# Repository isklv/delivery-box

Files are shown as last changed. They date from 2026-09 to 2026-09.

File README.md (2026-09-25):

# Parcel Drop Box — Secure Courier Delivery Box

A sheet-metal parcel box in the style of the 3FlexHome "Large Parcel Drop
Box — Top Access", designed so that **what goes in cannot come back out**
except through the owner's locked door.

- **Hinged top flap (top access)** — couriers drop parcels in from above.
- **One-way anti-fishing trap** — a spring-returned plate 170 mm below the
  rim that rotates downward only.
- **Concealed 4-point cam lock** on the front retrieval door — no hasp, no
  shackle, nothing to cut.
- **Anti-pry, anti-lift, anchorable** — inset door in a rebated frame, dog
  bolts on the hinge edge, welded floor, four M12 ground anchors and two
  wall brackets.

Built parametrically in [FreeCAD](https://www.freecad.org).
Russian version with a detailed walk-through of the mechanisms:
[README.ru.md](README.ru.md).

## How the protection works

| Attack | Countermeasure |
|---|---|
| Reaching in through the drop flap | `TrapDoor` closes the throat 170 mm down; parcels then sit a further 780 mm below it, out of arm's reach |
| Fishing a parcel back out with a hook, wire loop or sticky tape | The trap is a **one-way** valve: `TrapStops` block it from ever rotating above horizontal, so it can be pushed down but never pulled up. Anything lifted against it only jams it harder shut |
| Prying the top flap | 18 mm overhang + 14 mm return skirt on three sides, and the `ThroatCollar` turns the rim into a closed box section with no exposed edge |
| Bending the flap back for a straight shot into the box | Stop tabs on `FlapHinge` limit the swing to ~85° |
| Cutting a padlock | There is none. `CamLock` is a concealed cylinder in the door face; a quarter turn lifts `LockBar`, whose four lugs slide in behind the frame keeps |
| Prying the retrieval door | The door is an **inset pan** in a rebated frame (`DoorFrame`): a 2 mm gap, a 10 mm return on every edge, and an 18 mm flange behind it. Nothing to hook a bar behind, and it cannot be pushed in |
| Grinding the door hinges off | Three `DogBolts` on the hinge edge stay engaged in keeps in the frame — removing the hinges does not free the door |
| Levering the box up off its base | The floor is a welded 3 mm plate, not a panel — there is no seam underneath |
| Carrying the whole box away | Four M12 ground-anchor bosses under the floor, reachable only with the door open, plus two `WallBrackets` for bolting to a wall or post |
| Rain and standing water | Flap overhang, collar return, four floor drains, open-bottomed plinth |

## Dimensions

| Parameter | Value |
|---|---|
| Outer width × depth | 410 × 350 mm (414 × 354 over the corner ribs) |
| Overall height | 998 mm (40 plinth + 950 body + flap) |
| Clear drop opening | 356 × 296 mm |
| Trap plane | 170 mm below the rim |
| Parcel chamber | 406 × 344 × 780 mm |
| Retrieval door opening | 340 × 670 mm, sill 60 mm above the floor |
| Wall / flap sheet | 2 mm steel |
| Plinth, floor, door, trap sheet | 3 mm steel |
| Mass (steel only) | ≈ 52 kg |

## Parts

| Part | Role |
|---|---|
| `Plinth` | 40 mm perimeter base: feet, floor support ledge, four anchor bosses |
| `Floor` | Welded 3 mm floor plate, 4 drains, 4 recessed anchor holes |
| `Body` | 4 walls + corner ribs, open top, door opening in the front wall |
| `DoorFrame` | Rebate frame behind the opening + four lock keeps + three dog-bolt keeps |
| `WallBrackets` | Two slotted brackets for bolting the box to a wall or post |
| `ThroatCollar` | 25 mm inward flange + 40 mm return at the rim (stiffener / anti-pry) |
| `TopFlap` | Courier drop flap, 18 mm rain overhang, anti-pry skirt |
| `FlapHinge` | Rear piano hinge with stop tabs (~85° swing limit) |
| `FlapLatch` | Front drop latch |
| **`TrapDoor`** | **One-way anti-fishing trap, cranked rear hinge** |
| `TrapHinge` | Trap pin and fixed leaves, interleaved with the trap knuckles |
| `TrapSprings` | Two torsion springs that return the trap to closed |
| `TrapStops` | Ledges on three walls + rear cover: the trap can never rise above horizontal |
| `FrontDoor` | Inset retrieval door: pan, stiffener ribs, hinge leaves, handle |
| `DoorHinges` | Three wall leaves and pins |
| `DogBolts` | Three anti-lift pins on the hinge edge |
| `LockBar` | Vertical bar with four lugs and the cam yoke — the locking element |
| `CamLock` | Concealed cylinder; a quarter turn lifts the bar 22 mm |

## Drawings

Dimensioned sheets, generated from the same model by `drawings.py`:

| Sheet | |
|---|-|
| [01 General arrangement](drawings/01_general_arrangement.svg) | front / right / plan, overall sizes |
| [02 Trap mechanism](drawings/02_trap_mechanism.svg) | sections B-B and C-C, swing envelope, spring notes |
| [03 Lock mechanism](drawings/03_lock_mechanism.svg) | door from inside, keep section D-D, cam section E-E |

## Files

- `cad/ParcelDropBox.FCStd` — FreeCAD document, closed / armed
- `cad/ParcelDropBoxOpen.FCStd` — flap back, trap tripped, door swung open
- `cad/ParcelDropBox.step` — STEP export of all 18 parts
- `cad/verify.txt` — solid validity, interference and mass report, both states
- `drawings/*.svg` — dimensioned drawings
- `build_box.py` — parametric FreeCAD script (all states)
- `drawings.py` — generates the drawing sheets
- `render.py` — regenerates `images/`
- `images/` — rendered views

## Views

Closed:

| Isometric | Front | Bottom | Right |
|---|---|---|---|
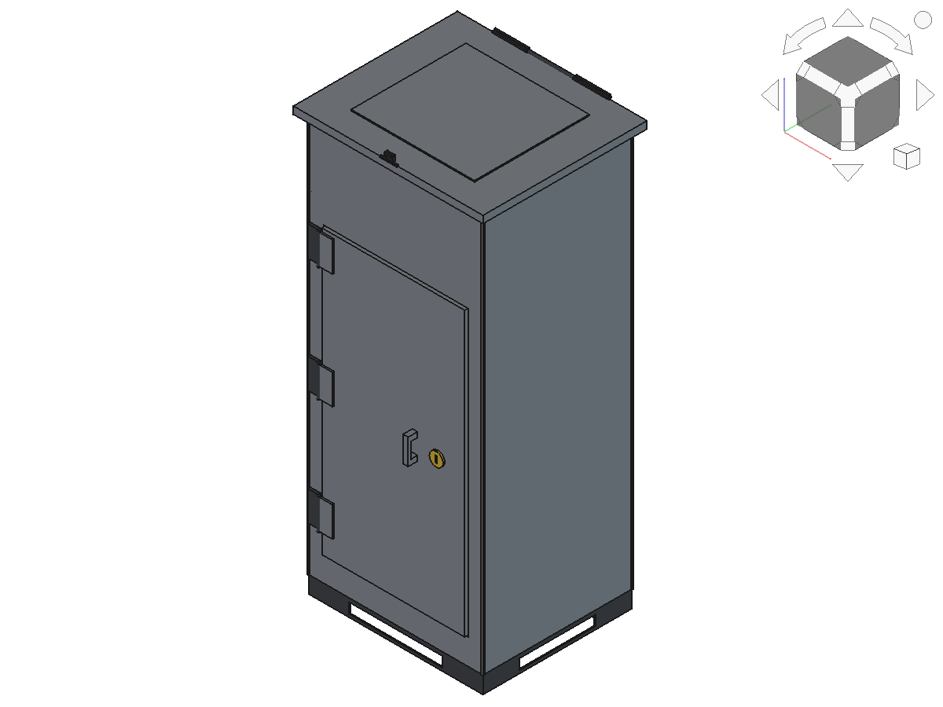
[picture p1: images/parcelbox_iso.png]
iso
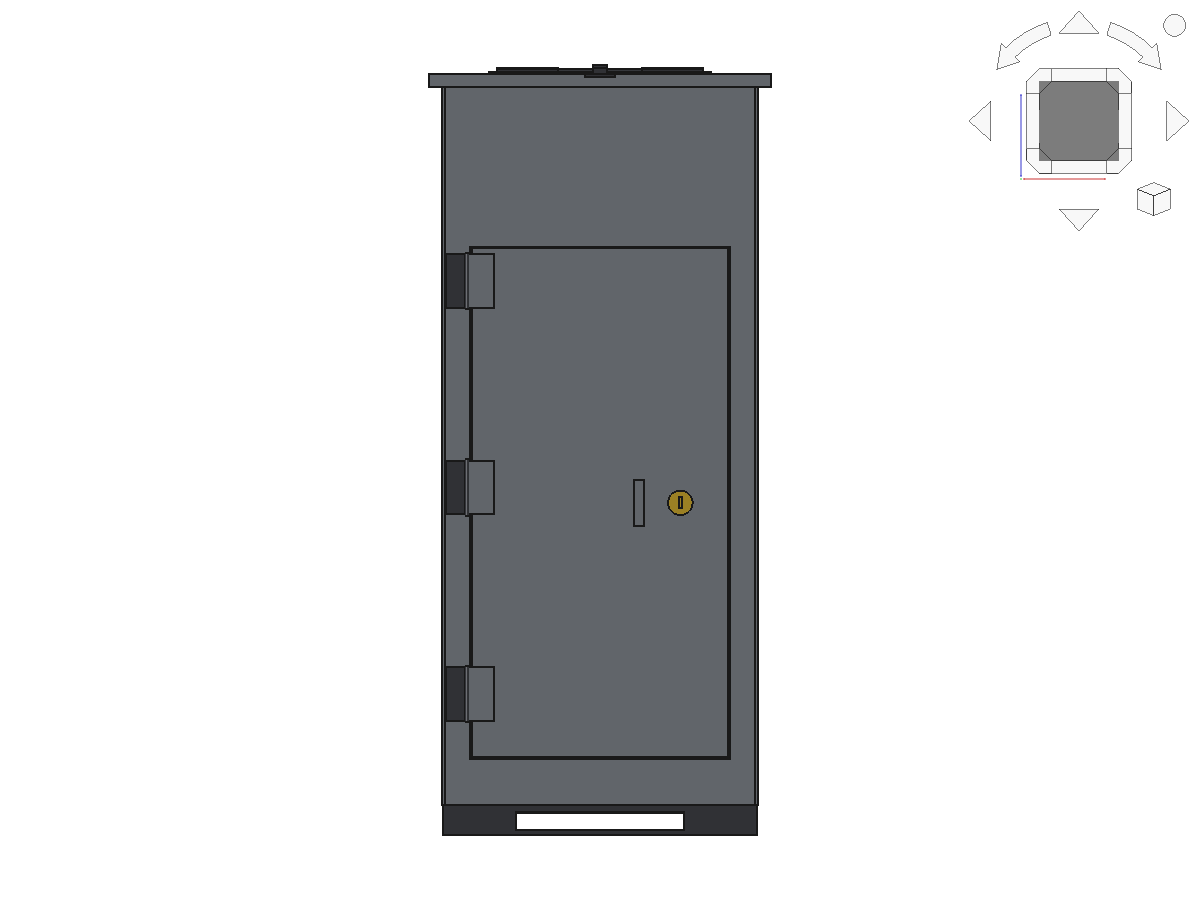
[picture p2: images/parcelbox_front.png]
front
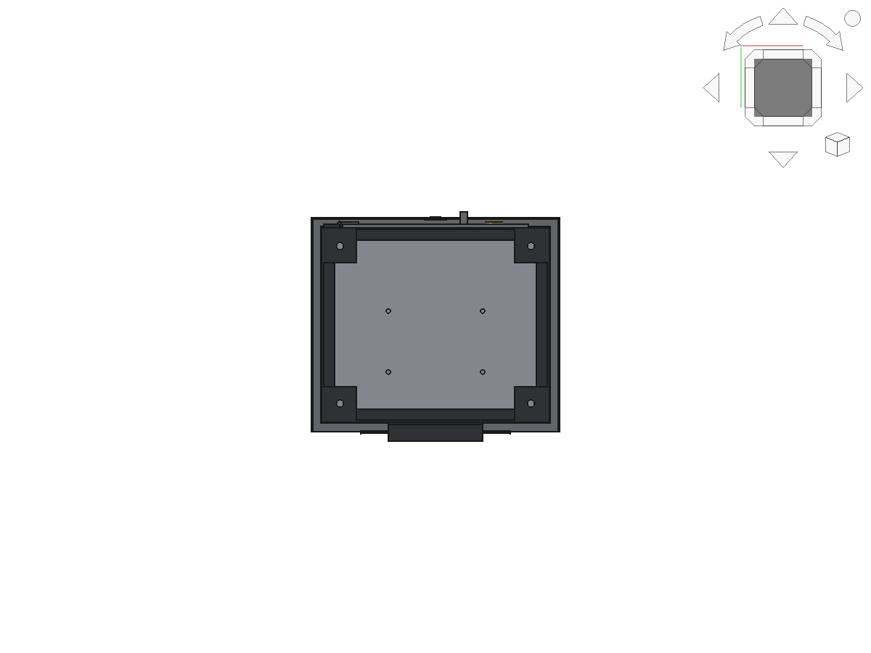
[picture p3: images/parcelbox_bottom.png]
bottom
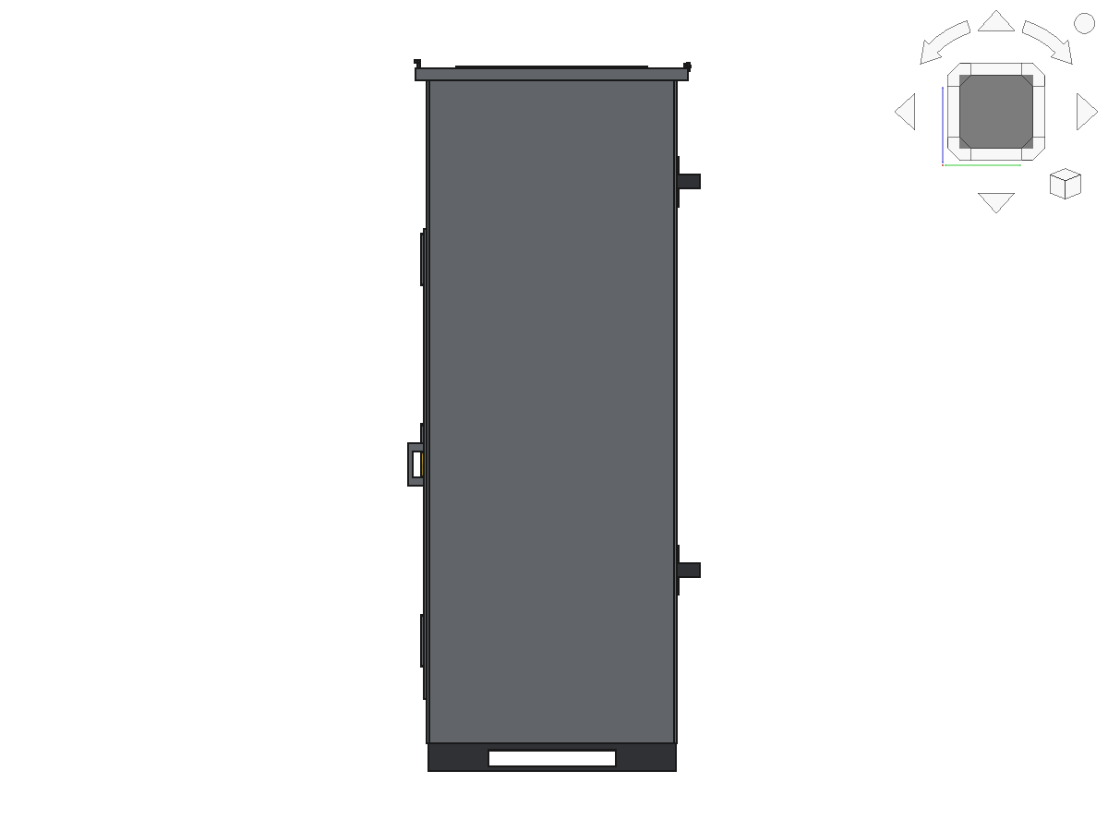
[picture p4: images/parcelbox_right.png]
right
|  |  |  |  |

Section on the X mid-plane — trap, springs, frame keeps and lock bar:

| Isometric | Side |
|---|---|
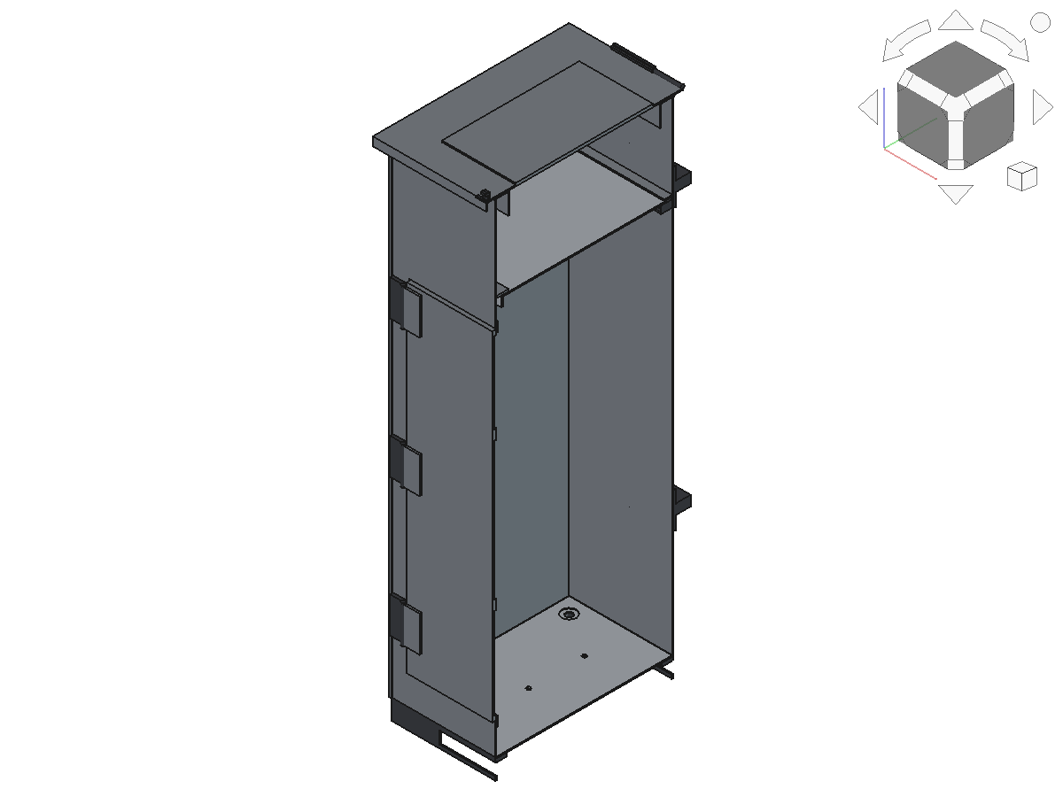
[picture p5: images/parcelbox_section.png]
section
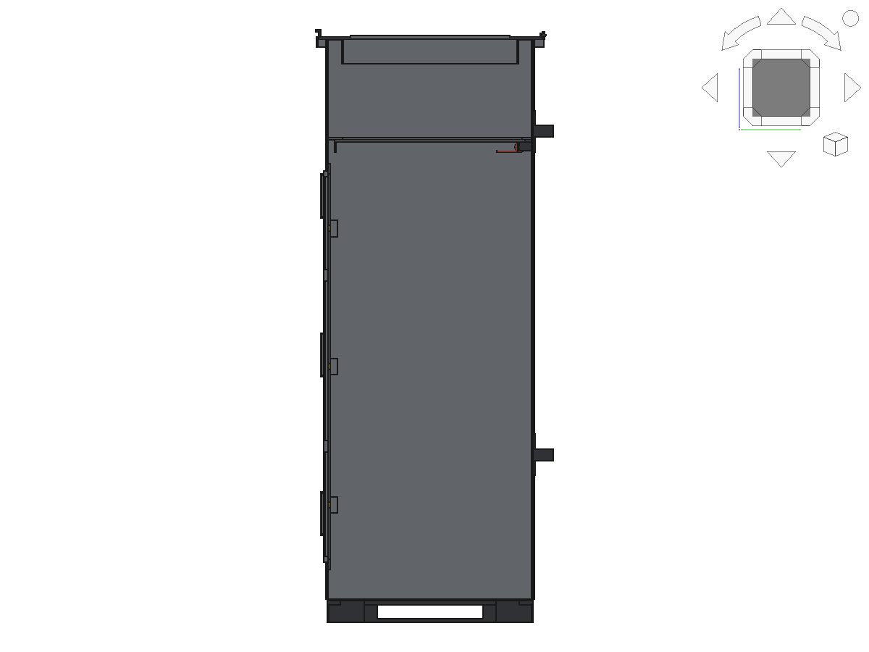
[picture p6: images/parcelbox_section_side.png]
section side
|  |  |

Mechanism close-ups — the one-way trap and the four-point lock:

| Trap, cut away | Trap, side | Lock, behind the door skin |
|---|---|---|
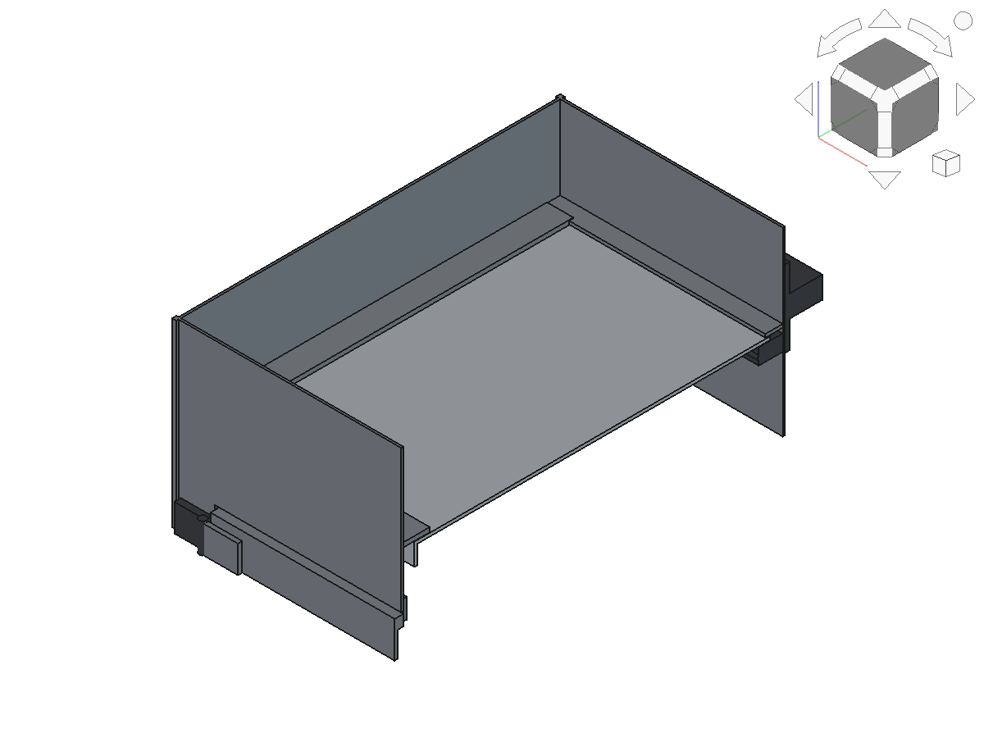
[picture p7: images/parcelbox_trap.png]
trap
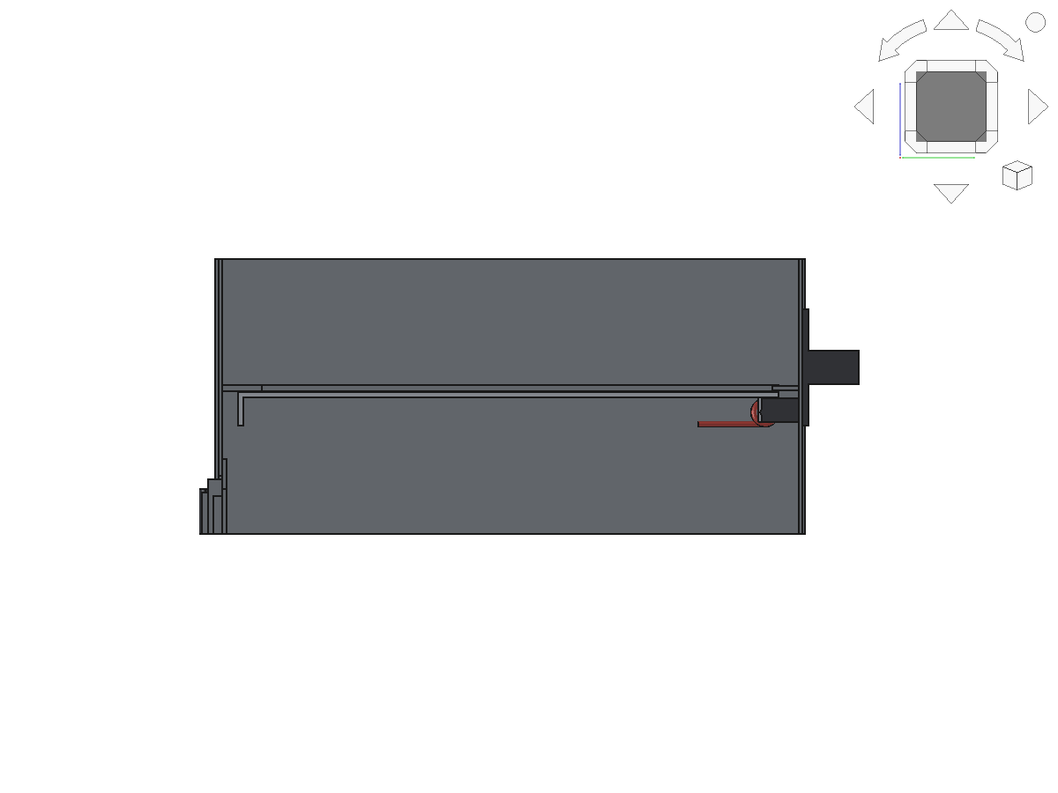
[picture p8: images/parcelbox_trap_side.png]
trap side
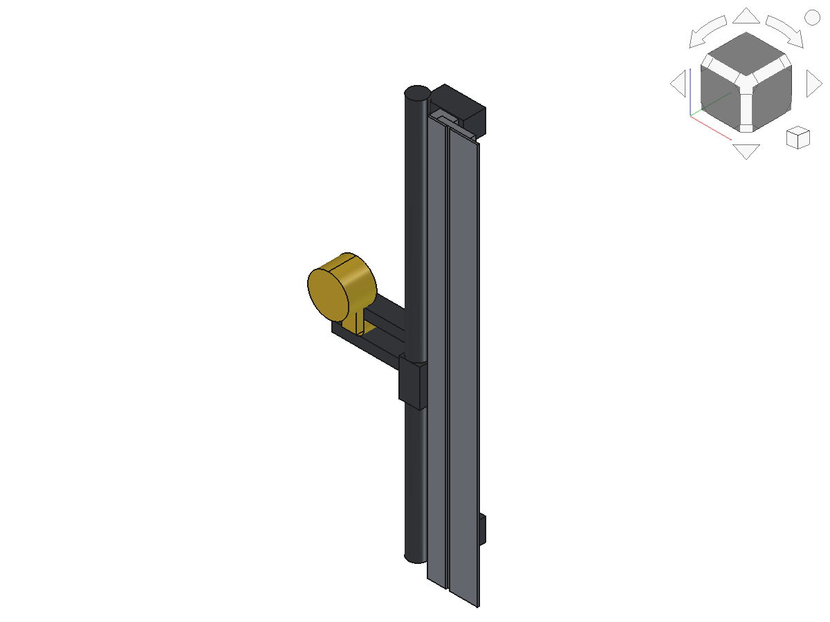
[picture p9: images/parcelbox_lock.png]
lock
|  |  |  |

Open — flap back, trap pushed open by a parcel, retrieval door swung wide:

| Isometric | Front | Back |
|---|---|---|
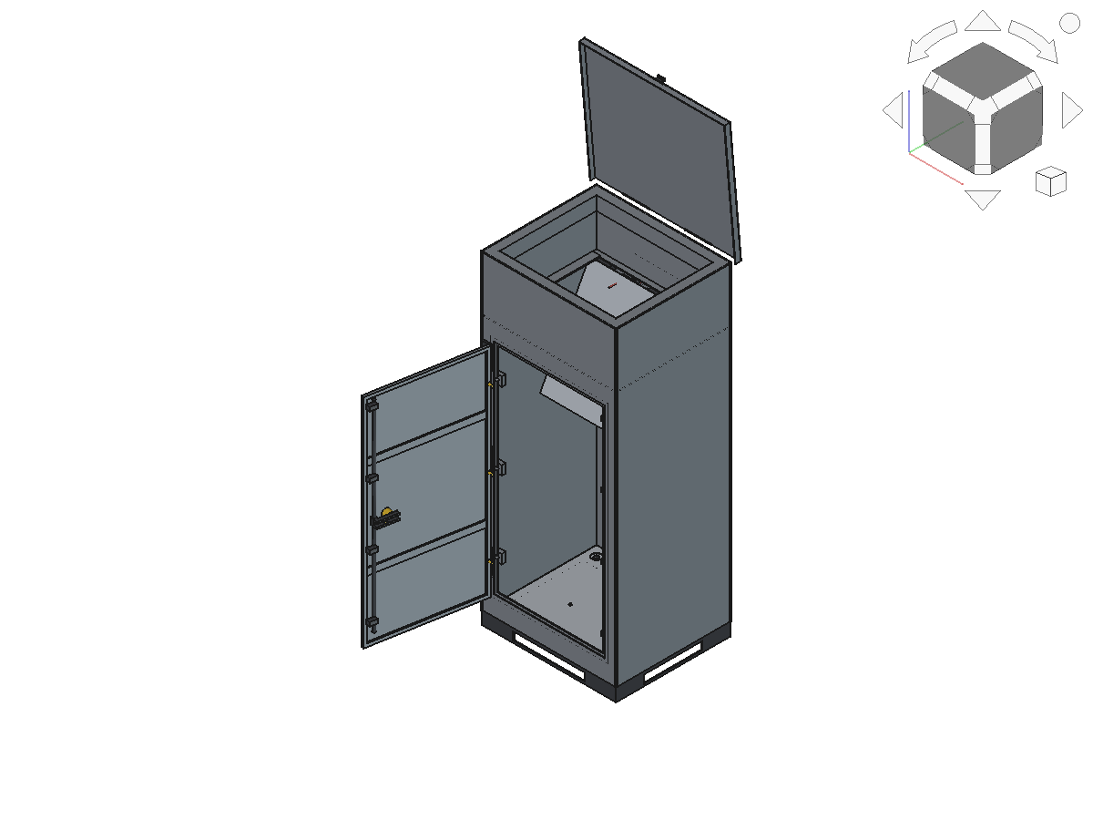
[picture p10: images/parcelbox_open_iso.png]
open iso
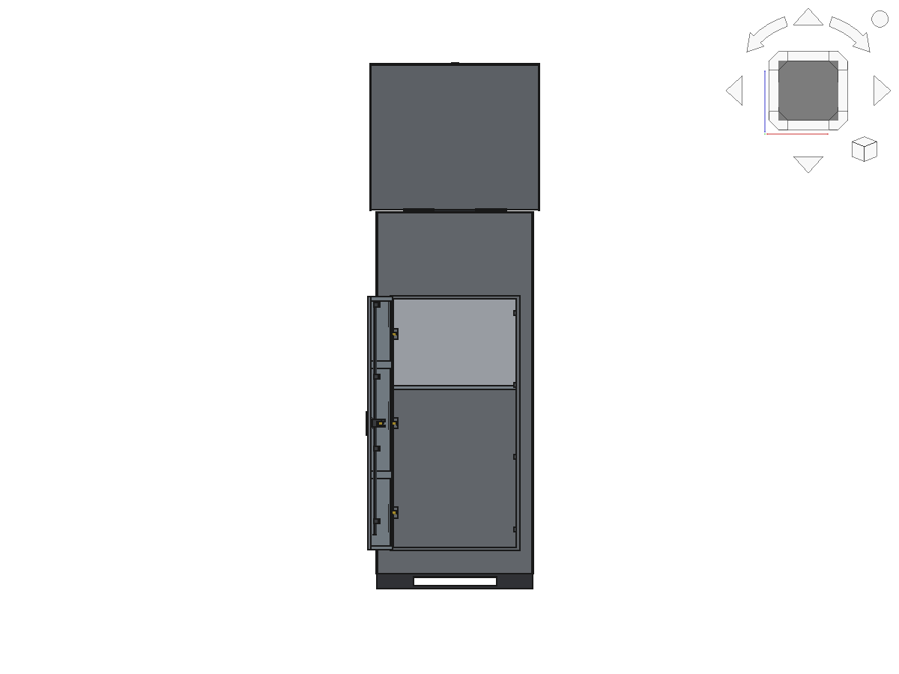
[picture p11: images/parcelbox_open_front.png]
open front
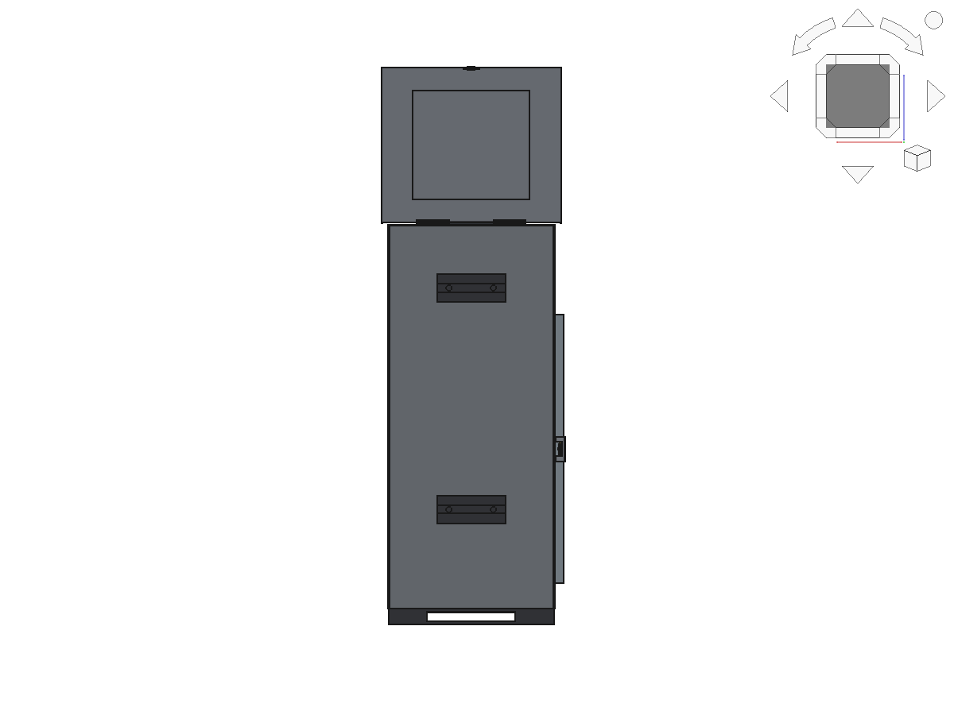
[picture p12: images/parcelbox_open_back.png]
open back
|  |  |  |

## Regenerate

```sh
FreeCADCmd build_box.py                     # geometry, STEP and verify.txt
FreeCADCmd drawings.py                      # dimensioned sheets in drawings/

# images (headless); keep stdin open, FreeCAD's console quits on EOF
sleep 400 | LIBGL_ALWAYS_SOFTWARE=1 \
    xvfb-run -a -s "-screen 0 1600x1200x24" FreeCAD -c render.py
```

On a desktop, `FreeCAD -c render.py` is enough. Both scripts write next to
themselves, into `cad/` and `images/`; `render.py` builds the geometry in
memory and does not touch `cad/`.

## Design and build notes

- **Trap spring tuning is the one adjustment that matters.** The trap is a
  3 mm plate of about 2.3 kg hinged at the rear, so gravity alone would
  leave it hanging open. The two torsion springs must hold it shut and
  still yield to a light parcel; anchor the reaction leg on a slotted
  bracket so the preload can be set on assembly. Aim for a trap that a
  500 g parcel opens.
- The trap hinge is **cranked** — the pin sits 12 mm below the plate — so
  the plate clears its own stop ledges as it swings and cannot be levered
  off the pin from above.
- The trap knuckles and the fixed hinge leaves **interleave** along the
  pin like a piano hinge; weld the pin ends over so it cannot be driven
  out from the throat.
- Weld the `TrapStops` ledges continuously, not in tacks: they are what
  turns the trap from a flap into a one-way valve.
- The lock bar is thrown **upward** to lock. Each lug then sits behind a
  keep on the frame; with the bar down the lugs pass clear, so the door
  closes without forcing anything.
- The 60 mm sill under the door opening keeps parcels from tumbling out
  when the door is opened on a full box.
- Ground anchors go in first: the M12 bosses are only reachable through
  the open door, which is also why they cannot be undone from outside.
- All 18 solids are verified valid in both states with no unintended
  interference; the only overlaps are hinge pins inside their knuckles and
  welded joints (see `cad/verify.txt`).

## What this does not stop

An angle grinder, a battery reciprocating saw, or a vehicle and a chain
will get through any 2–3 mm sheet-steel box, this one included. The design
targets the realistic threat — an opportunist reaching or fishing through
the delivery opening, levering the doors, or walking off with the whole
box — and makes those attacks fail. Anchor it, and site it where a noisy
attack is not private.

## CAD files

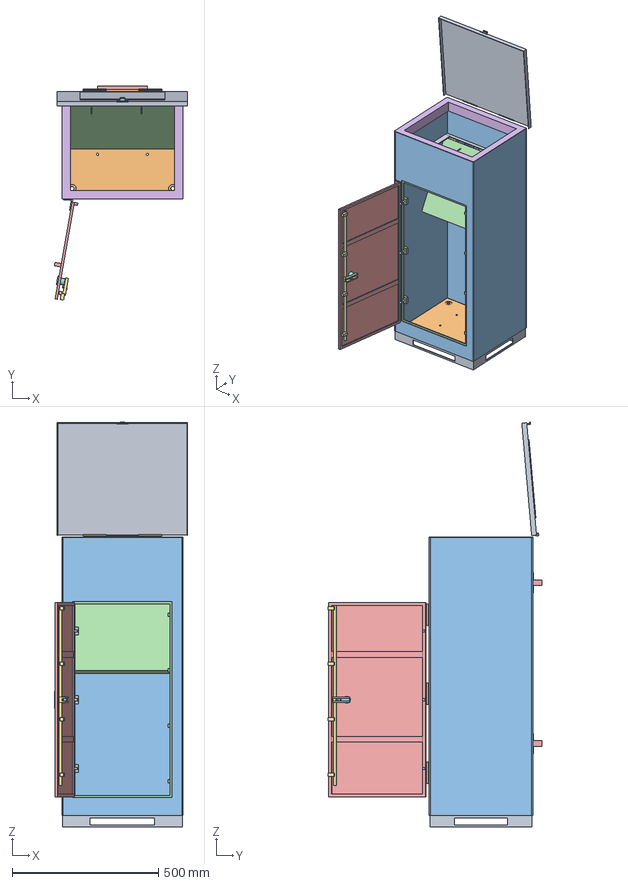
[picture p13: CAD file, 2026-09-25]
cad/ParcelDropBoxOpen.FCStd
455.6 x 732.3 x 1384.4 mm
TopFlap
FlapHinge
FlapLatch
TrapDoor
FrontDoor
DogBolts
LockBar
CamLock
Plinth
Floor
DoorFrame
WallBrackets
ThroatCollar
TrapHinge
TrapSprings
TrapStops
DoorHinges

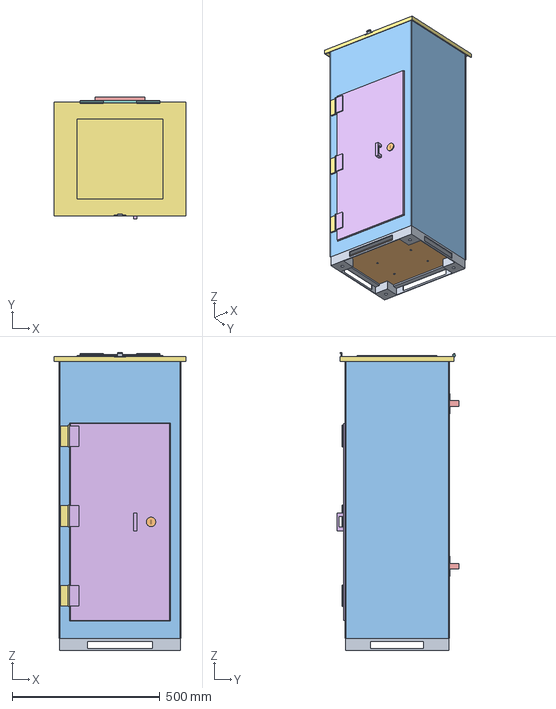
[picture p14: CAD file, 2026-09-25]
cad/ParcelDropBox.step
446.0 x 412.0 x 1008.0 mm

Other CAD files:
cad/ParcelDropBox.FCStd

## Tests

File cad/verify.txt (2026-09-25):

=== closed / armed ===
part                 valid   volume cm3   bbox z
Plinth               True       778.8        0..40    
Floor                True       411.7       37..40    
Body                 True      2462.8       40..990   
DoorFrame            True       131.2       90..780   
WallBrackets         True       284.4      250..870   
ThroatCollar         True       187.3      950..992   
TopFlap              True       785.4      978..998   
FlapHinge            True        18.1      992..1004  
FlapLatch            True         1.7      992..1008  
TrapDoor             True       416.0      800..820   
TrapHinge            True        47.5      802..816   
TrapSprings          True         7.4      797..819   
TrapStops            True       117.1      820..824   
FrontDoor            True       856.3      102..768   
DoorHinges           True        43.2      148..762   
DogBolts             True         1.8      196..674   
LockBar              True        68.3      120..735   
CamLock              True        12.5      409..451   

clamp TopFlap / FlapHinge : 1185.1 mm3
clamp TopFlap / FlapLatch : 480.0 mm3
clamp TrapDoor / TrapHinge : 3273.0 mm3
clamp FrontDoor / DoorHinges : 2771.1 mm3
steel mass approx 52.1 kg

=== open (flap back, trap tripped, door swung) ===
part                 valid   volume cm3   bbox z
Plinth               True       778.8        0..40    
Floor                True       411.7       37..40    
Body                 True      2462.8       40..990   
DoorFrame            True       131.2       90..780   
WallBrackets         True       284.4      250..870   
ThroatCollar         True       187.3      950..992   
TopFlap              True       785.4      996..1382  
FlapHinge            True        18.1      994..1004  
FlapLatch            True         1.7     1375..1384  
TrapDoor             True       416.0      525..821   
TrapHinge            True        47.5      802..816   
TrapSprings          True         7.4      797..819   
TrapStops            True       117.1      820..824   
FrontDoor            True       856.3      102..768   
DoorHinges           True        43.2      148..762   
DogBolts             True         1.8      196..674   
LockBar              True        68.3      142..757   
CamLock              True        12.5      419..451   

clamp TopFlap / FlapHinge : 1185.1 mm3
clamp TopFlap / FlapLatch : 480.0 mm3
clamp TrapDoor / TrapHinge : 3273.0 mm3
clamp TrapDoor / TrapSprings : 54.7 mm3
clamp TrapDoor / TrapStops : 1.7 mm3
clamp FrontDoor / DoorHinges : 2771.1 mm3
steel mass approx 52.1 kg

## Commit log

2026-09-08 Sheet-metal courier delivery drop box (FreeCAD)
    - 700x500x800mm, 2mm sheet, open top for drop-in
    - lockable rear-hinged bottom door (hasp + padlock)
    - parametric build script + STEP export + rendered views
    [DeliveryBox.FCStd, DeliveryBox.step]
2026-09-08 Redesign to match 3FlexHome top-access parcel drop box
    - compact 410x350x990mm powder-coat steel box on 4 feet
    - hinged TOP FLAP for courier drop-in (top access)
    - lockable rear-hinged BOTTOM DOOR (hasp + padlock) for retrieval
    - drainage holes in floor, rain overhang on flap
    - verified: valid solids, no structural overlap
    [DeliveryBox.FCStd, DeliveryBox.step, ParcelDropBox.FCStd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]
2026-09-25 Add anti-theft system: one-way trap, front door, 4-point lock
    The box had no protection beyond a drop flap and an external padlock, and
    its floor-panel retrieval door could not physically open - hinged 37 mm
    above ground, it had nowhere to swing.
    Security:
    - TrapDoor: spring-returned one-way trap 170 mm below the rim. Stop
    ledges block it above horizontal, so a parcel pushes through but a
    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
    [ParcelDropBox.FCStd, ParcelDropBox.step, ParcelDropBoxOpen.FCStd]
2026-09-25 Add dimensioned drawings, mechanism renders and a Russian README
    drawings.py generates three SVG sheets straight from the solids, so the
    drawings cannot drift from the model:
    - 01 general arrangement: front / right / plan with overall sizes
    - 02 trap mechanism: section B-B through the plate with the 62 deg swing
    envelope as a phantom, section C-C through a torsion spring, and notes
    on what makes the trap one-way
    - 03 lock mechanism: door from inside, keep section D-D with a lug
    engaged, cam section E-E showing the 22 mm throw
    Projection uses TechDraw.project; dimensions and callouts are driven by
    the same parameters build_box.py builds from.
    Also: two close-up documents (ParcelDropBo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
    [ParcelDropBox.FCStd, ParcelDropBox.step, ParcelDropBoxOpen.FCStd]
